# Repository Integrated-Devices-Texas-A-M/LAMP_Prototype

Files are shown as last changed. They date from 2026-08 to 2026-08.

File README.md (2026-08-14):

---

# *An Open-Source All-in-One Colorimetric Point-of-Care Device for Real-Time and Automated Monitoring of Loop-Mediated Isothermal Amplification*

An open-source, 3D-printed, all-in-one platform for real-time monitoring of colorimetric loop-mediated isothermal amplification (LAMP) reactions. The device integrates controlled heating, uniform white back-illumination, automated image acquisition, and on-device image analysis through a Raspberry Pi touchscreen graphical user interface (GUI).

The current platform monitors **five 0.2 mL reaction tubes in parallel** and quantifies the pink-to-yellow color transition of pH-sensitive colorimetric LAMP reactions using a normalized yellowing index. The software supports live preview, single-image capture, time-lapse acquisition, offline folder analysis, and combined real-time acquisition and analysis.

---

## 🔧 Features

* All-in-one integration of heating, illumination, imaging, control, and analysis
* Simultaneous monitoring of five colorimetric LAMP reactions
* Raspberry Pi –based operation with an integrated touchscreen GUI
* Fixed imaging geometry with a 34 mm × 34 mm field of view and 38 mm working distance
* Uniform white LED back-illumination beneath the reaction tubes
* Single-image and automated time-lapse image acquisition
* User-defined acquisition duration, capture interval, and experiment folder name
* Real-time tube segmentation and frame-by-frame signal extraction

---

## 📋 Material List

The values below correspond to the prototype configuration reported in the manuscript. Prices reflect the estimated contribution of each component to one assembled device and may change by supplier, location, or purchase date.

| Component | Component number | Quantity per device | Estimated cost per device |
|---|---:|---:|---:|
| Raspberry Pi 4B, 4 GB | RPI4-MODBP-4GB | 1 | $70.99 |
| Raspberry Pi power supply | 5V3A | 1 | $10.99 |
| Touchscreen | 782917535652 | 1 | $33.99 |
| Camera module | OV5647 | 1 | $24.99 |
| External M12 lens | M25360H06 | 1 | $7.99 |
| LED backlight module | B00R5CDIG4 | 1 | $4.85 |
| Jumper wires | 10CM4INCH | 6 | $0.45 |
| Temperature controller | B08W2BYG2L | 1 | $5.50 |
| Silicone heating mats | 1279 | 2 | $9.80 |
| AC 12 V power-supply charger | B0DHXXLY5Z | 1 | $9.28 |
| Foam insulation sheet | FSSA01 | 1 | $2.75 |
| ON/OFF switch | KCD1-101 | 1 | $0.90 |
| ABS-CF10 3D-printed case | ABS-CF10 | 1 set | $66.67 |
| **Total estimated cost per device** |  |  | **$249.15** |

---

## 🛠️ OpenLAMP Device Assembly

<p align="center">
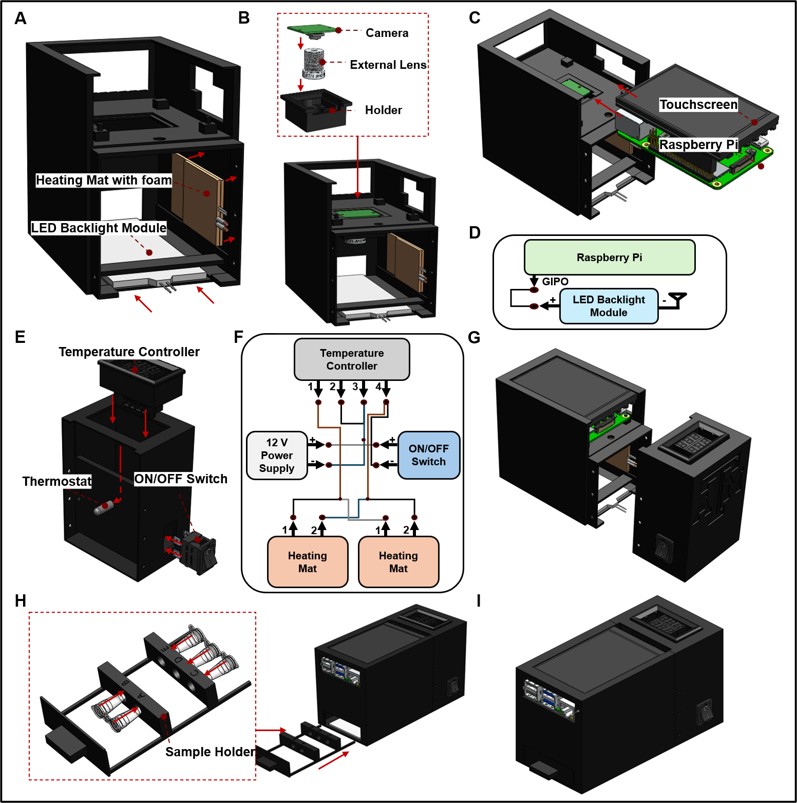
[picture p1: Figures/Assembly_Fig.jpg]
Figure S1. OpenLAMP assembly workflow
  
</p>

**A. Heating and illumination unit**

Install the two silicone heating mats inside the heating chamber. Place the foam insulation behind the heating mats to reduce heat loss and protect the printed enclosure. Install the white LED backlight module beneath the sample region so that illumination is directed upward through the reaction tubes.

**B. Camera and external lens**

Insert the OV5647 camera module, M25360H06 external lens, and camera holder into the imaging unit. Confirm that the lens is centered above the five-tube sample holder and that the working distance is maintained at approximately 38 mm.

**C. Touchscreen and Raspberry Pi**

Install the touchscreen and Raspberry Pi 4B in the upper section of the enclosure. Route the camera ribbon cable and display connections without bending or pinching the cables.

**D. LED control connection**

Connect the LED control wiring to the Raspberry Pi GPIO connection used by the software. The current script defines two GPIO-controlled light outputs using BCM GPIO **16** and **26**, with GPIO 16 selected as the default active illumination channel.

**E. Temperature-controller unit**

Install the programmable temperature controller, thermistor connection, and ON/OFF switch in the side heating enclosure.

**F. Heating-unit wiring**

Connect the 12 V power supply, temperature controller, ON/OFF switch, and both heating mats according to the wiring diagram. Confirm the controller terminal assignments before applying power.

**G. Join the device units**

Align the main imaging unit with the side heating/controller unit and secure both sections using the designated screws.

**H. Install the sample holder**

Place the five-tube sample holder into the lower opening of the assembled device. Confirm that the holder moves smoothly and consistently positions the reaction tubes within the camera field of view.

**I. Final assembly check**

Before operating the device, verify the following:

* Camera and external lens are secured.
* Touchscreen and Raspberry Pi connections are stable.
* LED backlight is centered beneath the tubes.
* Heating mats and insulation are fixed in position.
* Tube holder is fully inserted and aligned.
* All electrical connections are insulated and strain-relieved.

### Temperature calibration

The manuscript prototype used a controller setpoint of approximately **72 °C** to obtain an effective reaction-tube temperature of approximately **65 °C**. This offset is specific to the reported enclosure, heater placement, insulation, thermistor position, and ambient conditions.

Do not assume that the controller display equals the temperature inside the LAMP reaction tubes. Calibrate every newly assembled device using an independent temperature probe positioned at the reaction-tube region before performing LAMP experiments.

---

## 📦 Installation (Dependencies)

### Install the required Python packages

The current application imports PyQt5, Picamera2, gpiozero, OpenCV, NumPy, pandas, Matplotlib, and openpyxl.

```bash
sudo apt install -y \
  python3-picamera2 \
  python3-pyqt5 \
  python3-opencv \
  python3-gpiozero \
  python3-numpy \
  python3-pandas \
  python3-matplotlib \
  python3-openpyxl
```

## 🔌 Current Hardware and Software Configuration

The following settings are hard-coded in the current software and should be preserved when reproducing the reported configuration.

| Setting | Current value |
|---|---|
| Number of monitored tubes | 5 |
| Negative-control position | Tube 1 |
| Camera preview size | 640 × 480 pixels |
| Captured image size | 2592 × 1944 pixels |
| Image format | 24-bit RGB JPEG |
| Camera exposure time | 20,000 µs |
| Automatic white balance | Disabled |
| Fixed color gains | Red = 1.8; Blue = 1.3 |
| Illumination stabilization time | 2 s |
| Default LED GPIO | BCM GPIO 16 |
| Alternate LED GPIO | BCM GPIO 26 |
| Main application window | 790 × 470 pixels |
| Output root directory | `/home/pi5/Pictures/` |

### Tube seed coordinates

The tube-segmentation algorithm uses the following image coordinates for 2592 × 1944-pixel images:

| Tube | x coordinate | y coordinate |
|---:|---:|---:|
| 1 | 524 | 929 |
| 2 | 902 | 779 |
| 3 | 1316 | 914 |
| 4 | 1586 | 776 |
| 5 | 1937 | 920 |

> These coordinates are specific to the reported camera position, lens, working distance, tube holder, and image resolution. If the camera or sample holder is moved, the seed coordinates must be recalibrated.

---

## 🖥️ GUI Usage Instructions

<p align="center">
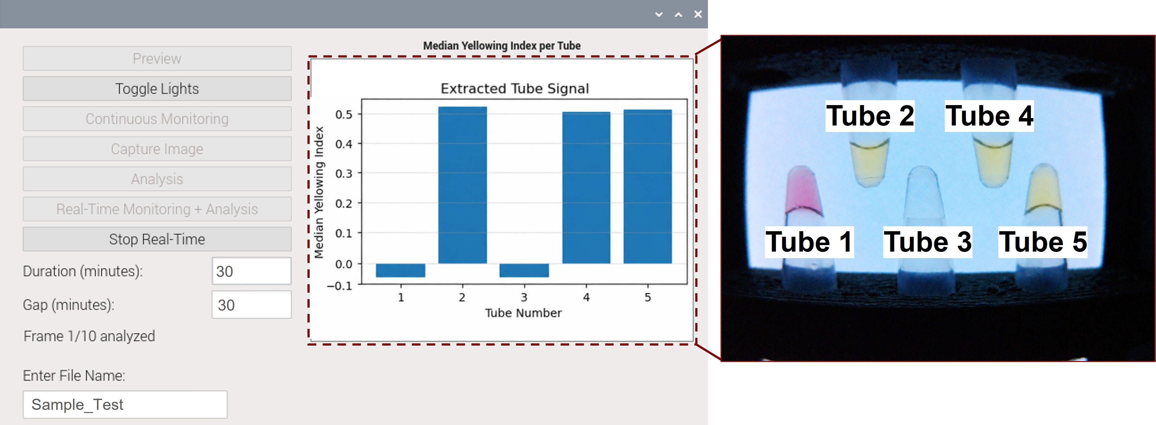
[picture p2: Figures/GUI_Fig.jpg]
Figure 3A. OpenLAMP Raspberry Pi graphical user interface
  
</p>

The GUI separates user controls on the left from the real-time tube-signal plot on the right.

### 1. Start the heating system

The Python application controls imaging, illumination, acquisition, and analysis. The heating system is operated through the external temperature controller.

1. Turn on the temperature-controller unit.
2. Set the calibrated controller setpoint.
3. Wait until the reaction-tube region reaches the required LAMP temperature.
4. Load the sealed reaction tubes into the sample holder.
5. Insert the sample holder completely into the device.

### 2. Enter the file name or sample ID

Use **Enter File Name** to define the image name or experiment-folder name.

Use a short, unique identifier without special characters, for example:

```text
US23_100pg_Run01
```

### 3. Preview

Select **Preview** to open the live camera window.

Use the preview to confirm:

* All five tubes are visible.
* The LED backlight is uniform.
* The image is in focus.
* No tube is blocked by the holder or enclosure.

Close the preview window before starting an acquisition.

### 4. Toggle Lights

Select **Toggle Lights** to switch between the two GPIO-defined illumination outputs.

The script uses:

* GPIO 16 as the default active light
* GPIO 26 as the alternate light

For the reported white-backlight configuration, use the GPIO channel connected to the white LED backlight module.

### 5. Capture Image

Select **Capture Image** to save one still image.

The image is saved as:

```text
/home/pi5/Pictures/FILE_NAME.jpg
```

This mode does not automatically create an experiment folder or perform image analysis.

### 6. Continuous Monitoring

Use **Continuous Monitoring** for automated time-lapse image acquisition without immediate analysis.

Enter:

* **Duration (minutes):** total requested acquisition duration
* **Gap (minutes):** delay between successive acquisitions
* **Enter File Name:** output-folder name

The software calculates the number of frames as:

```text
Number of frames = round(Duration / Gap)
```

For each frame, the active LED is turned on, the software waits 2 s, captures the image, turns the LED off, and waits until the next acquisition.

Images are saved sequentially as:

```text
1.jpg
2.jpg
3.jpg
...
```

### 7. Analysis

Select **Analysis** to process all `.jpg` images already stored in the experiment folder.

The software:

1. Reads all JPEG images in natural numerical order and processes them.
2. Detects the five tube regions.
3. Calculates the raw median yellowing index for every tube.
4. Generates summary plots and CSV.

### 8. Real-Time Monitoring + Analysis

Use **Real-Time Monitoring + Analysis** to acquire and analyze every frame during the experiment.

For each frame, the software:

1. Turns on the active LED.
2. Waits 2 s for illumination stabilization.
3. Captures a JPEG image.
4. Turns off the LED.
5. Segments the five tube regions.
6. Calculates the current yellowing-index values.
7. Updates the status text.
8. Updates the latest five-tube bar plot.
9. Updates the running CSV file.
10. Saves the final Excel workbook when the run ends or is stopped.

### 9. Stop Real-Time

Select **Stop Real-Time** to end the combined acquisition and analysis process after the current processing step.

When at least one frame has been completed, the application saves a partial final Excel workbook before stopping.

### 10. Results and real-time plot

The status area displays:

* Current frame number
* Analysis time
* Time remaining before the next frame

The right panel displays the **raw median yellowing index from the latest frame** as a five-bar plot.

## 🗂️ Save Image and Results Folder Structure

### Single-image capture

```text
/home/pi5/Pictures/
└── Sample_Name.jpg
```

### Continuous monitoring without analysis

```text
/home/pi5/Pictures/
└── Experiment_Name/
    ├── 1.jpg
    ├── 2.jpg
    ├── 3.jpg
    ├── ...
    ├── Analysis_Yellowing_Index.csv
    ├── Analysis_Median_Yellowing_Index.png
    └── Analysis_Yellowing_Index.xlsx

```

### Continuous monitoring and real-time analysis

```text
/home/pi5/Pictures/
└── Experiment_Name/
    ├── 1.jpg
    ├── 2.jpg
    ├── 3.jpg
    ├── ...
    ├── RealTime_Yellowing_Index_Running.csv
    ├── RealTime_Median_Yellowing_Index.png
    ├── RealTime_Yellowing_Index_Final.xlsx
    └── RealTime_Mask_Overlays/
```

## 📚 Citation

Citation information will be updated after publication.

Althumayri MO, Xu W, Zhao J, Scaccia N, Inan YS, Song J, Figueiredo Costa S, Sabino E, Ceylan Koydemir H. *An Open-Source All-in-One Colorimetric Point-of-Care Device for Real-Time and Automated Monitoring of Loop-Mediated Isothermal Amplification.* Manuscript submitted.

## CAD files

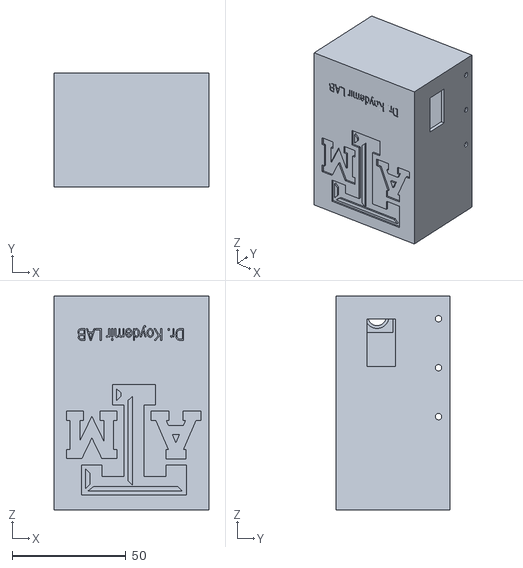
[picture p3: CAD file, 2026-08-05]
3D Printing Parts/Heating_unit.STL
68.0 x 50.0 x 94.0

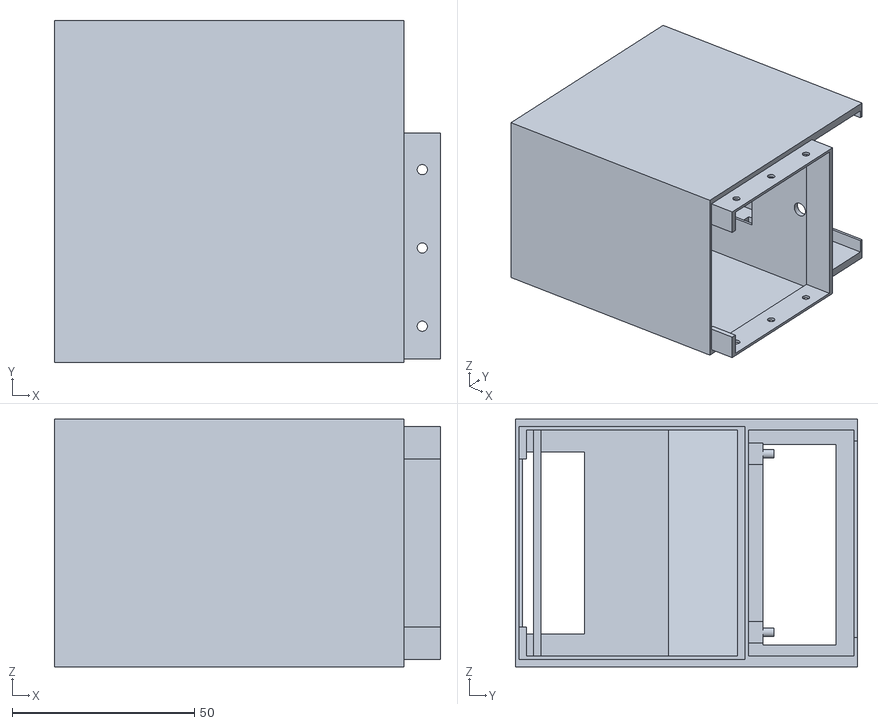
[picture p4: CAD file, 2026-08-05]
3D Printing Parts/Imaging_unit.STL
106.0 x 94.0 x 68.0

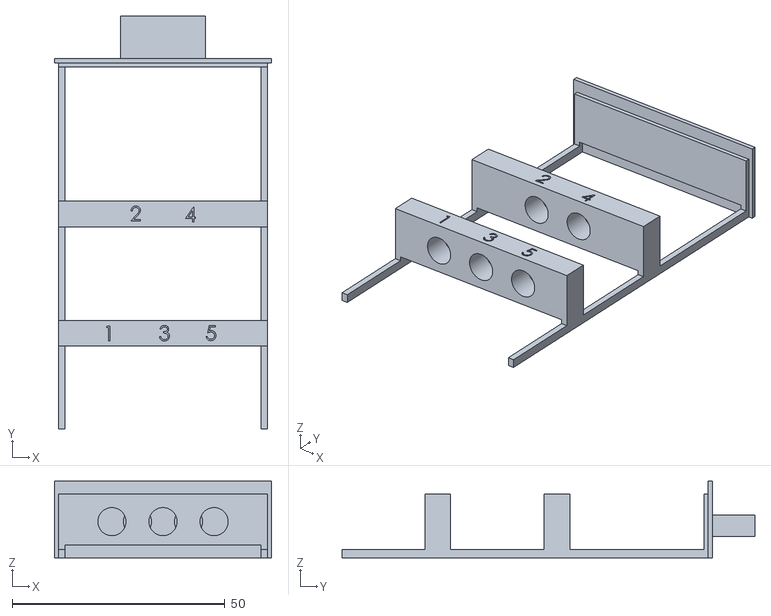
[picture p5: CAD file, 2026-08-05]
3D Printing Parts/Tube_holder.STL
51.0 x 97.0 x 18.0

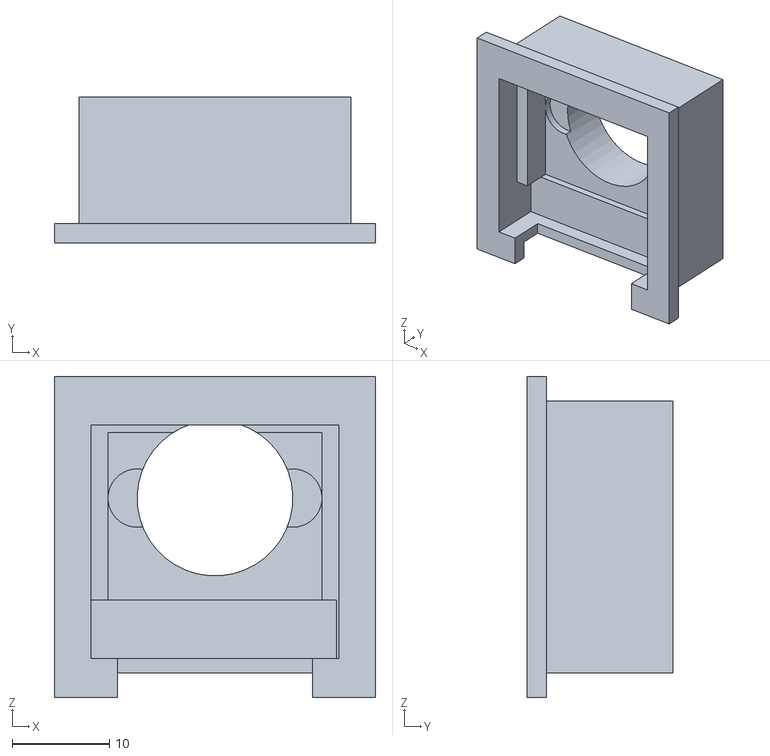
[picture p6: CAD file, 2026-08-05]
3D Printing Parts/CameraAndLens_holder.STL
33.0 x 15.0 x 33.0

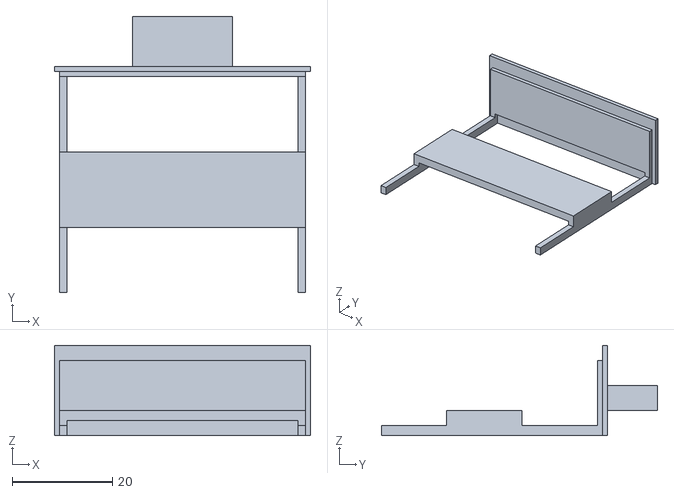
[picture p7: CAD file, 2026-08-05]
3D Printing Parts/Door_holder.STL
51.0 x 55.0 x 18.0

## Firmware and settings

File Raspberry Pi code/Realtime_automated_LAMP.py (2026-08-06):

#!/usr/bin/env python3
"""Real-time image acquisition and colorimetric analysis for a LAMP device.

This application controls two illumination channels and a Raspberry Pi camera,
captures single images or time-lapse image series, segments five reaction tubes,
and calculates the median yellowing index in each tube. It can perform either
post-run folder analysis or analysis immediately after each captured frame.

Yellowing index definition:
    YI = (G - B) / (R + G + B)

Hardware assumptions
--------------------
* Raspberry Pi running Picamera2
* Camera configured for RGB888 acquisition
* Two LED channels connected through GPIO pins 16 and 26
* Five reaction tubes at fixed seed-point coordinates

The analysis algorithm and numerical settings are retained from the working
experimental version; this revision primarily improves readability,
documentation, naming, and maintainability for publication.
"""

from __future__ import annotations

import os
import re
import shutil
import time
from datetime import datetime

from gpiozero import LED
from picamera2 import Picamera2
from PyQt5 import QtCore
from PyQt5.QtCore import QThread, pyqtSignal
from PyQt5.QtGui import QImage, QPixmap
from PyQt5.QtWidgets import (
    QApplication,
    QHBoxLayout,
    QLabel,
    QLineEdit,
    QPushButton,
    QVBoxLayout,
    QWidget,
)

# -----------------------------------------------------------------------------
# Application and hardware configuration
# -----------------------------------------------------------------------------
OUTPUT_ROOT = "/home/pi5/Pictures"
LED_1_GPIO_PIN = 16
LED_2_GPIO_PIN = 26
CAMERA_PREVIEW_SIZE = (640, 480)
CAMERA_EXPOSURE_US = 20_000
CAMERA_COLOUR_GAINS = (1.8, 1.3)
ILLUMINATION_STABILIZATION_SECONDS = 2
NUMBER_OF_TUBES = 5
BASELINE_FRAME_COUNT = 5
NEGATIVE_CONTROL_INDEX = 0  # Tube 1; Python uses zero-based indexing.

# Seed coordinates are stored as [x, y]. They were originally selected in
# MATLAB, so one is subtracted before indexing a NumPy image array.
TUBE_SEED_POINTS = (
    (524, 929),
    (902, 779),
    (1316, 914),
    (1586, 776),
    (1937, 920),
)
HSV_TOLERANCE = 30 / 255.0
HSV_NEIGHBORHOOD_SIZE = 15
SMOOTHING_WINDOW_SIZE = 4


def switch_mode():
    """Switch between the two illumination channels."""
    global active_led
    if led1.is_lit:
        led1.off()
        led2.on()
        active_led = led2
    elif led2.is_lit:
        led2.off()
        led1.on()
        active_led = led1
    else:
        led1.on()  # Default to turning on LED1 if both are off
        led2.off()
        active_led = led1


class MonitorWorker(QThread):
    """Capture a time-lapse image series without performing image analysis."""
    update_result = pyqtSignal(str)
    finished = pyqtSignal()

    def __init__(self, frames, sleep_time, new_folder, gap, picam2, led1):
        super().__init__()
        self.frames = frames
        self.sleep_time = sleep_time
        self.new_folder = new_folder
        self.gap = gap
        self.picam2 = picam2
        self.led1 = led1
        self._running = True

    def run(self):
        exposure_delay = ILLUMINATION_STABILIZATION_SECONDS
        for i in range(self.frames):
            if not self._running:
                break
            self.led1.on()
            time.sleep(exposure_delay)
            image_file = os.path.join(self.new_folder, f"{i + 1}.jpg")
            cfg = self.picam2.create_still_configuration()
            self.picam2.switch_mode_and_capture_file(cfg, image_file)
            self.led1.off()
            self.update_result.emit(f"Captured frame {i + 1}/{self.frames}. Waiting for {self.gap} minutes...")
            time.sleep(self.sleep_time)
        self.finished.emit()

    def stop(self):
        self._running = False


# ==========================================================
# SAVED-IMAGE ANALYSIS WORKER
# Processes an existing image folder with the exact same analyzer used by
# real-time monitoring. It runs in a QThread so the GUI remains responsive.
# ==========================================================
class AnalysisWorker(QThread):
    """Analyze saved images using the same analyzer as real-time monitoring.

    The images are processed sequentially with ``RealTimeAnalyzer`` in natural
    filename order. Therefore, the separate analysis button uses the same tube
    segmentation, fallback masks, yellowing-index extraction, baseline
    correction, negative-control correction, smoothing, CSV output, Step 9
    plot, and final Excel export as the real-time acquisition workflow.
    """
    update_result = pyqtSignal(str)
    update_plot = pyqtSignal(str)
    analysis_finished = pyqtSignal(str)
    analysis_error = pyqtSignal(str)
    progress = pyqtSignal(int, int)

    def __init__(self, image_dir):
        super().__init__()
        self.image_dir = image_dir

    def run(self):
        try:
            image_files = sorted(
                (
                    name for name in os.listdir(self.image_dir)
                    if name.lower().endswith(('.jpg', '.jpeg'))
                ),
                key=natural_sort_key,
            )
            if not image_files:
                raise ValueError("No .jpg or .jpeg images found in the selected folder.")

            analyzer = RealTimeAnalyzer(self.image_dir)
            total_images = len(image_files)

            for image_index, image_name in enumerate(image_files, start=1):
                self.update_result.emit(
                    f"Analyzing saved image {image_index}/{total_images}: {image_name}"
                )
                image_path = os.path.join(self.image_dir, image_name)
                analyzer.process_frame(image_path, image_index)
                self.update_plot.emit(analyzer.running_plot)
                self.progress.emit(image_index, total_images)

            final_excel = analyzer.finalize()
            self.analysis_finished.emit(
                "Saved-image analysis completed using the shared real-time method. "
                f"Plots saved in: {analyzer.plot_folder}. "
                f"Final Excel saved: {final_excel}"
            )
        except Exception as e:
            self.analysis_error.emit(f"Analysis error: {str(e)}")


def natural_sort_key(text):
    """Return a key that sorts names containing numbers in natural order."""
    return [int(c) if c.isdigit() else c.lower() for c in re.split(r'(\d+)', text)]


def moving_average_omitnan(data, window_size=SMOOTHING_WINDOW_SIZE):
    """Apply a centered moving average while ignoring missing values."""
    import numpy as np

    out = np.full_like(data, np.nan, dtype=float)
    n_rows, n_cols = data.shape
    half_left = (window_size - 1) // 2
    half_right = window_size // 2

    for c in range(n_cols):
        for r in range(n_rows):
            start = max(0, r - half_left)
            end = min(n_rows, r + half_right + 1)
            out[r, c] = np.nanmean(data[start:end, c])
    return out
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
